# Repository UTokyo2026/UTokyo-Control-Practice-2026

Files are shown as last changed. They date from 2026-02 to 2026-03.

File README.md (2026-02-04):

# Wheeled Inverted Pendulum - Course Materials

Course materials for the Wheeled Inverted Pendulum practical exercise at the University of Tokyo, Department of Precision Engineering.

## 📁 Contents

### 📄 Lecture notes (English)
- **text2026_en.pdf** – Full lecture text (English) for the Wheeled Inverted Pendulum exercise. Same content as the printed handout; all appendix PDFs are embedded. Update this file from the LaTeX build when you release a new version (see “Keeping the PDF in sync” below).

### 🛠️ debug_tools/
Debugging and visualization tools with complete documentation:

- **1_motor_controller/** - Interactive motor testing tool
- **2_analog_input_visualizer/** - 4-channel analog input visualization
- **3_six_channel_oscilloscope/** - Complete inverted pendulum control program with 6-channel real-time visualization

Each tool includes:
- `.cpp` - mbed source code
- `.bin` - Pre-compiled binary (ready to flash)
- `.pde` - Processing visualization program
- `README.md` / `README.pdf` - Complete documentation

### 📚 appendix/
All appendix materials (same as in the lecture notes):

- **Datasheets:** `AE-drv8832_a.pdf`, `Circuit_diagram.pdf`, `LD1117V33.pdf`, `RE280ra.pdf`, `TPR-105f.pdf`
- `parts_list.pdf` - Parts list
- `processing_oscilloscope_manual.pdf` - Processing installation and oscilloscope manual

### 📊 matlab_simulink/
MATLAB/Simulink models for simulation and controller design (to be added)

### 🎥 video/
Demonstration videos of working inverted pendulum

## 🚀 Quick Start

### Using the Complete Control Program

1. **Flash to mbed:**
   ```
   debug_tools/3_six_channel_oscilloscope/3_six_channel_oscilloscope.bin
   ```
   Drag and drop this file to your mbed USB drive.

2. **Run visualization:**
   Open `3_six_channel_oscilloscope.pde` in Processing and click Run.

3. **Reset mbed** to synchronize the display.

### Understanding the Code

Open `3_six_channel_oscilloscope.cpp` to see the complete implementation:
- Lines 3-11: Control parameters (KP, KD, VLIMIT, etc.)
- Lines 70-132: Main control loop (PD control algorithm)
- Lines 134-161: Initialization and startup

### Adjusting Parameters

Edit the `#define` values at the top of `3_six_channel_oscilloscope.cpp`:

```cpp
#define SAMP_FREQ 2000.0f  // Sampling frequency (Hz)
#define VLIMIT 0.1f        // Motor voltage limit (0-1)
#define VOFFSET 0.0f       // Friction compensation
#define KP 1.0f            // Proportional gain
#define KD 0.0f            // Derivative gain
```

Then recompile in Keil Studio Cloud and flash the new `.bin` file.

## 📖 Documentation

Detailed documentation is available in the `debug_tools/` folder:

- **Main README:** `debug_tools/README.md` - Overview of all tools
- **Tool-specific READMEs:** Each tool has its own detailed documentation

All READMEs are available in both Markdown (`.md`) and PDF (`.pdf`) formats.

## 🔧 Requirements

### Hardware
- mbed LPC1768 microcontroller
- DRV8832 motor driver module
- RE-280RA DC motor
- TPR-105F photo-interrupters (×2)
- LD1117V33 voltage regulator
- Battery pack and other components (see circuit diagram)

### Software
- [Keil Studio Cloud](https://studio.keil.arm.com/) - For compiling mbed programs
- [Processing](https://processing.org/download) - For visualization tools
- [MATLAB/Simulink](https://www.mathworks.com/) - For simulation (optional)

## 📝 License

These materials are provided for educational purposes as part of the University of Tokyo Precision Engineering practical exercise course.

## 🎓 Course Information

- **Course:** Practical Exercise in Precision Engineering
- **Institution:** University of Tokyo, Department of Precision Engineering
- **Academic Year:** 2026 S1S2

## 📧 Support

For questions or issues:
1. Check the README files in `debug_tools/`
2. Review the circuit diagram in `appendix/`
3. Consult the course lecture notes
4. Ask your instructor or TA

## 🔗 Related Resources

- [mbed Documentation](https://os.mbed.com/docs/)
- [Processing Documentation](https://processing.org/reference/)
- [DRV8832 Datasheet](https://www.ti.com/product/DRV8832)

---

**Last Updated:** February 2026  
**Version:** 2026.1

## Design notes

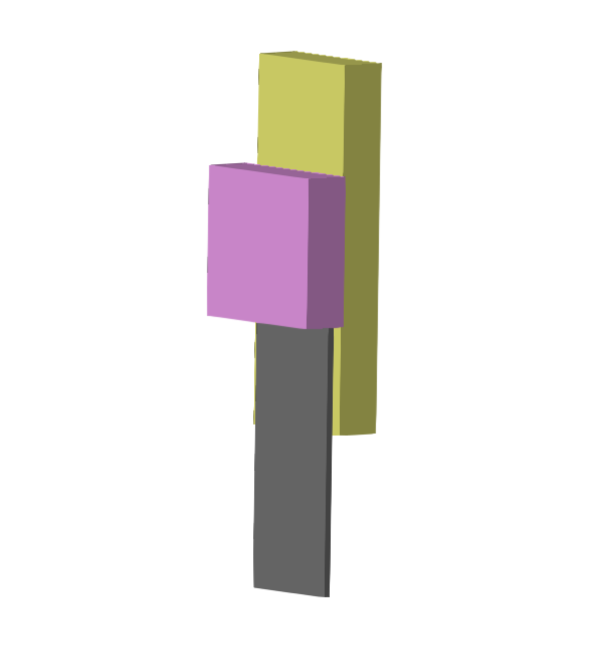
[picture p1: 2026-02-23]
matlab_simulink/Body.png

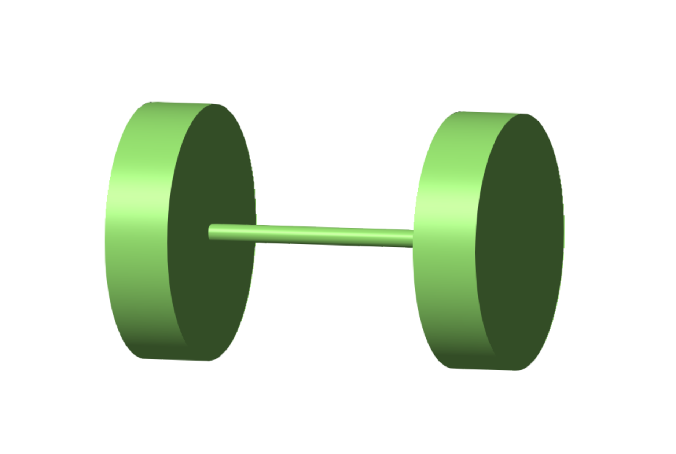
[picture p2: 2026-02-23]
matlab_simulink/Wheel.png

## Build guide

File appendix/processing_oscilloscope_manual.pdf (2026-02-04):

## 簡易オシロスコープの使い方

【事前インストール作業】
1. （Windows のみ）mbed シリアルポートドライバをインストール

https://os.mbed.com/handbook/Windows-serial-configuration こちらのページからドライバをダウンロードし，指示に従ってインストールしてください．
2. Processing のインストール

https://processing.org/
こちらから Processing をダウンロードしてインストールしてください（ZIP ファイルを解凍して，好 きなフォルダに設置するだけです）．最初から自分のパソコンに Processing が入っている人は，Ver. 3 系であることを確認してください．Ver. 2 系と Ver. 3 系は，一部互換性がありません．
3. オシロスコーププログラムの設置
Google Drive の plotter6ch (https://drive.google.com/drive/folders/17Zr5LieNyZgATRA_iedG5hgk1iPhXVAk?usp=sharing) の中にある 2 つのファイルをダウンロードします．自分のパソコンの中 に（場所はどこでも良いので）plotter6ch という名称のフォルダを作り，その中にダウンロードした 2 個のファイルを入れてください．Processing は，フォルダ名とプログラムファイル名が同じで無い と動作しませんので，フォルダ名を必ず “plotter6ch” としてください．

【使い方】
◼ | Mbed に制御用プログラムをコンパイルしてダウンロードし，パソコンと USB 接続します．
| plotter6ch.pde（環境により拡張子は表示されないかもしれません）をダブルクリックで開き，下
| 図赤丸の部分（丸に三角形の実行ボタン）を押すと，簡易オシロスコープが立ち上がります．
| （【Windows】初回のみ，右クリック→プログラムから開く→Processing）

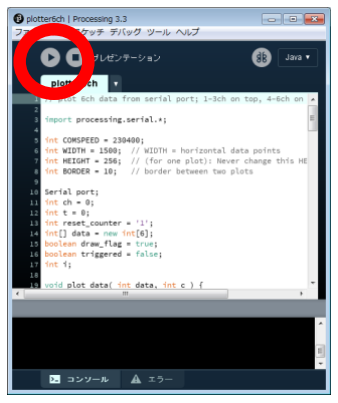
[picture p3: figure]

実行ボタンを押したときに，次ページに示すオシロスコープ画面が出ない人や，エラーで止まって しまう人は，Processing ウィンドウ下部の console 画面をみてください．そこに，パソコンの中に あるシリアルポートの一覧が出ています．例えば，Mac の場合だと

[0] “dev/cu.Bluetooth-Incoming-Port”
[1] “dev/tty.Bluetooth-Incoming-Port”
[2] “dev/tty.usbmodem1412”
などと表示されますので，”dev/tty.usbmodemXXXX” (XXXX は数字が入る)を探してください．そ のポートの番号（行頭にある[3]などの数字）を，プログラムの 63 行目に書き込みます．

port = new Serial( this, Serial.list()[0], COMSPEED);
下線部の 0 となっている部分を書き換えてください．
Windows の人は，表示されるポートを上から（0 番から）順に試してみてください．

◼ | 画面は上下に 2 分割されています．上半分に１～３チャンネルが，下半分に４～６チャンネルが，
| それぞれ（赤，緑，青）の順で表示されます．

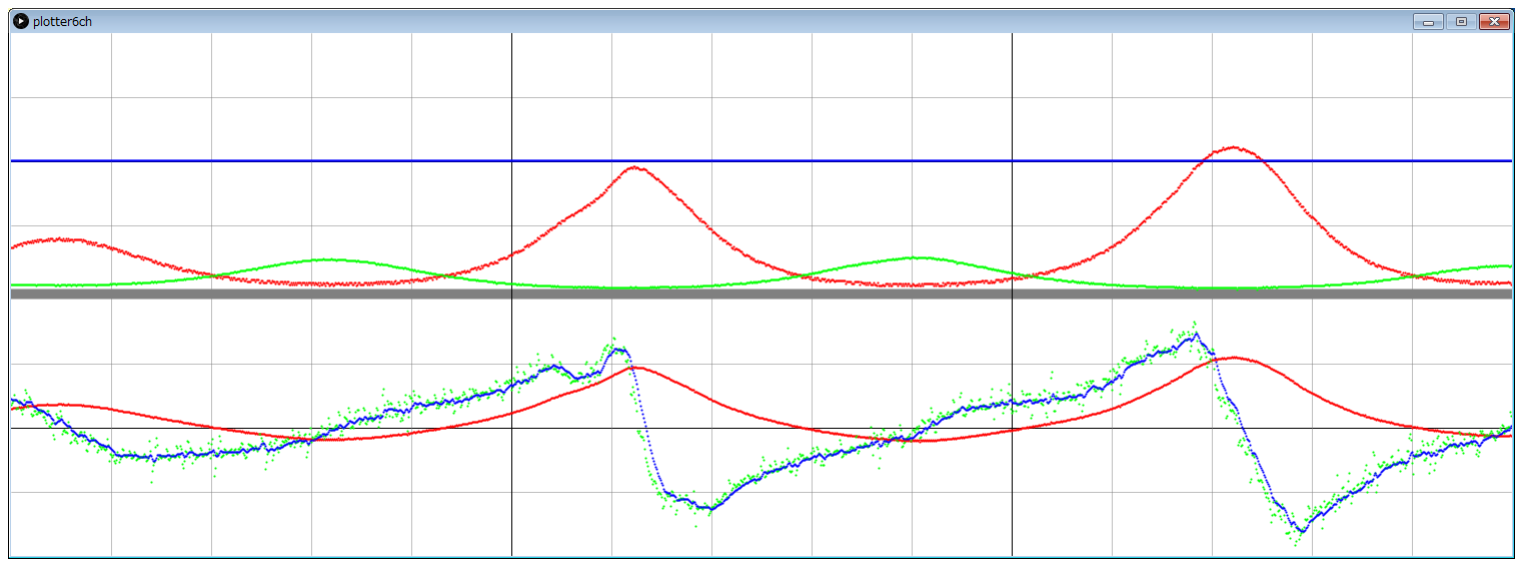
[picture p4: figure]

◼ | オシロスコープが動作している最中に MBED をリセットすることで，チャンネル順序が正しい順 序にリセットされます（MBED 側のプログラムで書いた順に１～６チャンネルになります）． リセットしていない状況では，チャンネル順序は意図した順序になっていない場合があります．
◼ | 画面上でクリックすると，現在の描画が右端まで進んだところで描画が停止します．また，スクリ ーンショットが，data.png という名前で保存されます（同名ファイルがある場合は上書きされま す）．再度画面上でクリックすると，再び画面の更新が始まります． スクリーンショットの保存先は，plotter6ch フォルダです．
◼ | 標準では画面の横幅は 1500 点です．MBED プログラムが 2000Hz で動いている場合，画面の横幅 は 0.75 秒に相当します．
◼ | 各データは 1 バイト（0-255）のデータとして送受信されています．MBED 側から送信する際には， データを 0-255 の範囲に整えた上で，char 型に cast してください．画面表示は，上下それぞれに おいて，一番下が 0，一番上が 255 になります．
◼ | この簡易オシロスコーププログラムは，毎制御周期に必ず 6 個のデータ（かつ，全て 1 バイトデー タ）が送られてくるという想定で動いています．MBED 側からは，（必要が無い場合でも）必ず６ チャンネル分のデータを送ってください．そうしないと，おかしなグラフになります．

1-3 CH

4-6 CH

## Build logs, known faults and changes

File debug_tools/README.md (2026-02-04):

# Debug Tools for Inverted Pendulum

This directory contains three debugging tools for the wheeled inverted pendulum experiment. Each tool consists of:
- **`.cpp` file**: mbed microcontroller program (C++ source code)
- **`.bin` file**: Pre-compiled binary ready to flash to mbed LPC1768
- **`.pde` file**: Processing visualization program (runs on PC)

## Tools Overview

### 1. Motor Controller (`motor_controller/`)
**Purpose**: Test motor driver circuit and control motor interactively

**mbed Program** (`motor_controller.cpp`):
- Receives commands via USB serial (115200 baud)
- Commands:
  - `F xx` - Forward at xx% duty cycle (0-100)
  - `B xx` - Backward at xx% duty cycle (0-100)
  - `S` - Stop motor
- Pin connections:
  - `p13`: Motor forward signal
  - `p14`: Motor reverse signal
  - `p18`: Motor PWM voltage (AnalogOut)

**Processing Visualizer** (`motor_controller.pde`):
- Provides GUI with sliders and buttons
- Displays real-time motor status
- Sends commands to mbed via serial

**Usage**:
1. Flash `motor_controller.bin` to mbed (or compile `.cpp` yourself)
2. Connect motor driver circuit
3. Run `motor_controller.pde` in Processing
4. Use GUI to test motor operation

---

### 2. Analog Input Visualizer (`analog_input_visualizer/`)
**Purpose**: Visualize 4 analog input channels in real-time

**mbed Program** (`analog_input_visualizer.cpp`):
- Reads 4 analog inputs at ~200 Hz
- Sends data via USB serial (115200 baud)
- Uses frame-based protocol: `[0xAA 0x55] + 4 bytes`
- Pin connections:
  - `p16`: Analog input CH1
  - `p17`: Analog input CH2
  - `p19`: Analog input CH3 (photo-interrupter 1)
  - `p20`: Analog input CH4 (photo-interrupter 2)

**Processing Visualizer** (`analog_input_visualizer.pde`):
- Displays 4-channel real-time waveforms
- Shows pendulum angle graphically
- Helps verify sensor alignment and operation

**Usage**:
1. Flash `analog_input_visualizer.bin` to mbed
2. Connect analog sensors to inputs (p16-p20)
3. Run `analog_input_visualizer.pde` in Processing
4. Observe real-time sensor readings

---

### 3. Six-Channel Oscilloscope (`six_channel_oscilloscope/`)
**Purpose**: Monitor complete control system with 6 data channels

**mbed Program** (`six_channel_oscilloscope.cpp`):
- Implements full PD control loop at 2000 Hz
- Reads angle sensors (2 photo-interrupters)
- Controls motor based on feedback
- Sends 6 channels of data via USB serial (230400 baud)
- Uses frame-based protocol: `[0xAA 0x55] + 6 bytes`
- Data channels:
  1. Photo-interrupter 1 output
  2. Photo-interrupter 2 output
  3. Angle (difference of sensors)
  4. Angular velocity (ω)
  5. Filtered angular velocity
  6. Reference line (128)

**Processing Visualizer** (`six_channel_oscilloscope.pde`):
- Displays 6 channels in two 3-channel plots
- Upper plot: CH1 (Red), CH2 (Green), CH3 (Blue)
- Lower plot: CH4 (Red), CH5 (Green), CH6 (Blue)
- Essential for tuning control parameters

**Usage**:
1. Flash `six_channel_oscilloscope.bin` to mbed
2. Connect complete circuit (motor + sensors)
3. Run `six_channel_oscilloscope.pde` in Processing
4. Reset mbed to synchronize display
5. Tune PD gains while monitoring system response

---

## How to Use

### Option 1: Use Pre-compiled Binaries (Easiest)
1. Connect mbed LPC1768 to PC via USB
2. mbed appears as USB drive (e.g., `MBED` or `LPC1768`)
3. Drag and drop `.bin` file to mbed drive
4. Press reset button on mbed
5. Run corresponding `.pde` file in Processing

### Option 2: Compile from Source
If you want to modify the programs or understand the code:

1. **For mbed programs**:
   - Use [Keil Studio Cloud](https://studio.keil.arm.com/) (online IDE)
   - Or use [mbed CLI](https://os.mbed.com/docs/mbed-os/latest/build-tools/index.html) locally
   - Import mbed-os library
   - Compile `.cpp` file
   - Download generated `.bin` file
   - Flash to mbed

2. **For Processing programs**:
   - Install [Processing](https://processing.org/download)
   - Open `.pde` file
   - Click Run (▶) button
   - Select correct serial port in code if needed

---

## Serial Communication Protocol

All tools use USB serial communication between mbed and PC:

### Basic Principle
- **UART (Universal Asynchronous Receiver-Transmitter)**: Serial protocol for byte-by-byte data transmission
- **USB-to-Serial**: mbed LPC1768 has built-in USB-to-serial converter
- **Pins**: `USBTX` and `USBRX` connect to USB interface
- **Baud Rate**: Communication speed (bits per second)
  - Motor Controller: 115200 bps
  - Analog Input Visualizer: 115200 bps
  - Oscilloscope: 230400 bps (higher for 2 kHz data rate)

### Frame-Based Protocol (Visualizers)
To reliably transmit multiple data values, a frame-based protocol is used:

```
[Header: 0xAA 0x55] [Data Byte 1] [Data Byte 2] ... [Data Byte N]
```

- **Frame Header**: Two special bytes (`0xAA 0x55`) mark start of frame
- **Data Bytes**: Each sensor/variable value encoded as 0-255
- **Synchronization**: Processing searches for header pattern to align data stream

### Text-Based Protocol (Motor Controller)
Simple ASCII commands for human readability:
- Commands sent as text strings (e.g., `"F 50\n"`)
- Easy to test with any serial terminal
- mbed parses commands using `sscanf()`

---

## Pin Assignments Summary

| Function | Pin | Type | Used By |
|---|-----|---|---|
| Motor Forward | p13 | DigitalOut | Motor Controller, Oscilloscope |
| Motor Reverse | p14 | DigitalOut | Motor Controller, Oscilloscope |
| Motor Voltage | p18 | AnalogOut | Motor Controller, Oscilloscope |
| Analog CH1 | p16 | AnalogIn | Analog Input Visualizer |
| Analog CH2 | p17 | AnalogIn | Analog Input Visualizer |
| Photo-interrupter 1 | p19 | AnalogIn | Analog Input Visualizer, Oscilloscope |
| Photo-interrupter 2 | p20 | AnalogIn | Analog Input Visualizer, Oscilloscope |
| USB Serial TX | USBTX | Serial | All tools |
| USB Serial RX | USBRX | Serial | All tools |

**Note**: `p18` is the only AnalogOut pin on mbed LPC1768, so motor voltage control must use this pin.

---

## Troubleshooting

### mbed not recognized as USB drive
- Try different USB cable (some cables are power-only)
- Press reset button on mbed
- Check USB port on PC

### Processing cannot find serial port
- Check port name in `.pde` file (usually auto-detected)
- On Windows: Look for `COM3`, `COM4`, etc.
- On macOS: Look for `/dev/tty.usbmodem*`
- On Linux: Look for `/dev/ttyACM*`
- Ensure no other program is using the port

### No data displayed in Processing
- Reset mbed after starting Processing program
- Check baud rate matches between mbed and Processing
- Verify USB cable supports data (not just power)

### Motor moves opposite direction
- Swap motor driver connections (`p13` ↔ `p14`)
- Or swap motor wire polarity

### Sensor readings look wrong
- Check sensor power supply (3.3V, not 5V)
- Verify pull-up resistors are installed
- Adjust sensor alignment mechanically
- Check resistor values (typical: 1kΩ - 12kΩ)

---

## Modifying the Programs

### Changing Control Parameters (Oscilloscope)
Edit these `#define` values in `six_channel_oscilloscope.cpp`:

```cpp
#define SAMP_FREQ 2000.0f  // Sampling frequency (Hz)
#define VLIMIT 0.1f        // Motor voltage limit
#define KP 1.0f            // Proportional gain
#define KD 0.0f            // Derivative gain
```

After changing, recompile and flash to mbed.

### Adding More Channels
The frame protocol can be extended:
1. Add more data bytes in mbed program after frame header
2. Update Processing to read additional bytes
3. Add visualization for new channels

### Changing Serial Baud Rate
Must match in both mbed and Processing:

**mbed**: `pc.baud(115200);`  
**Processing**: `myPort = new Serial(this, portName, 115200);`

---

## Further Reading

- [mbed Serial API](https://os.mbed.com/docs/mbed-os/latest/apis/serial-uart-apis.html)
- [Processing Serial Library](https://processing.org/reference/libraries/serial/index.html)
- [UART Communication Basics](https://learn.sparkfun.com/tutorials/serial-communication)

---

## License

These tools are provided for educational purposes as part of the University of Tokyo wheeled inverted pendulum experiment.

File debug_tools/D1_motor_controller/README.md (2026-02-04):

# Motor Controller Debug Tool

## Purpose
Interactive tool for testing motor driver circuit and controlling motor speed/direction without modifying code.

## Files

### 1_motor_controller.cpp (mbed program)
**What it does:**
- Receives text commands via USB serial communication
- Controls motor based on received commands
- Provides simple command-line interface for motor testing

**Pin Connections:**
- `p13` (DigitalOut): Motor forward signal → connects to motor driver IN1
- `p14` (DigitalOut): Motor reverse signal → connects to motor driver IN2
- `p18` (AnalogOut): Motor PWM voltage → connects to motor driver VSET
- `USBTX/USBRX`: USB serial communication (built-in)

**Serial Settings:**
- Baud rate: 115200 bps
- Protocol: Text-based ASCII commands

**Commands:**
```
F xx    Forward at xx% duty cycle (0-100)
        Example: "F 50" → forward at 50% speed

B xx    Backward at xx% duty cycle (0-100)
        Example: "B 30" → backward at 30% speed

S       Stop motor
        Example: "S" → stop immediately
```

**How it works:**
1. Program waits for characters from serial port
2. When newline (`\n`) is received, parses the command
3. Extracts command letter (F/B/S) and optional value
4. Applies corresponding motor control:
   - Forward: sets `motor_f=1`, `motor_r=0`, `motor_v=duty`
   - Backward: sets `motor_f=0`, `motor_r=1`, `motor_v=duty`
   - Stop: sets `motor_f=0`, `motor_r=0`, `motor_v=0`
5. Sends confirmation message back via serial

### 1_motor_controller.bin (pre-compiled binary)
**What it is:**
- Compiled executable file for mbed LPC1768
- Contains machine code ready to run on microcontroller

**How to use:**
1. Connect mbed to PC via USB
2. mbed appears as USB drive (e.g., "MBED" or "LPC1768")
3. Drag and drop `1_motor_controller.bin` onto mbed drive
4. LED on mbed flashes during programming
5. Press reset button on mbed to start program

**Why use .bin instead of .cpp:**
- No compilation needed—instant deployment
- Guaranteed to work (already tested and compiled)
- Faster workflow for testing

**When to compile .cpp yourself:**
- Want to change pin assignments
- Need to modify commands or add features
- Want to adjust motor control logic
- Learning how the code works

### 1_motor_controller.pde (Processing visualizer)
**What it does:**
- Provides graphical user interface (GUI) for motor control
- Displays real-time motor status
- Sends commands to mbed via serial

**Features:**
- Sliders for adjusting motor speed (0-100%)
- Buttons for forward/backward/stop
- Real-time display of current motor state
- Visual feedback of PWM duty cycle
- Direction indicator

**How to use:**
1. Install Processing from https://processing.org/download
2. Open `1_motor_controller.pde` in Processing
3. Check serial port name in code (usually auto-detected)
4. Click Run button (▶) to start GUI
5. Use sliders and buttons to control motor

## Usage Workflow

### Quick Start (using .bin file):
1. Flash `1_motor_controller.bin` to mbed
2. Connect motor driver circuit to mbed:
   - p13 → motor driver IN1
   - p14 → motor driver IN2
   - p18 → motor driver VSET
3. Connect motor to driver output
4. Connect power supply
5. Run `1_motor_controller.pde` in Processing
6. Use GUI to test motor

### Advanced (compiling from source):
1. Open Keil Studio Cloud (https://studio.keil.arm.com/)
2. Create new project for mbed LPC1768
3. Import mbed-os library
4. Copy contents of `1_motor_controller.cpp`
5. Compile and download .bin file
6. Flash to mbed as above

## Testing Checklist

Use this tool to verify:
- [ ] Motor rotates forward when commanded
- [ ] Motor rotates backward when commanded
- [ ] Motor speed changes with PWM duty cycle
- [ ] Motor stops completely when commanded
- [ ] No abnormal heating of motor driver IC
- [ ] Power supply voltage remains stable
- [ ] No excessive current draw

## Troubleshooting

**Motor doesn't move:**
- Check battery/power supply is on
- Verify motor driver connections
- Check motor wires are connected
- Ensure mbed is programmed correctly (reset after flashing)

**Motor moves opposite direction:**
- Swap p13 and p14 connections
- Or swap motor wire polarity

**Processing can't connect:**
- Check serial port name in .pde file
- Ensure no other program is using the port
- Try different USB cable (must support data)
- On Windows: look for COM3, COM4, etc.
- On macOS: look for /dev/tty.usbmodem*
- On Linux: look for /dev/ttyACM*

**Motor runs but speed doesn't change:**
- Check p18 (AnalogOut) connection to VSET
- Verify PWM duty cycle is being sent correctly
- Check motor driver power supply

## Technical Details

### Text-Based Protocol
The motor controller uses a simple text-based protocol for human readability:

**Advantages:**
- Easy to test with any serial terminal (PuTTY, screen, etc.)
- Human-readable for debugging
- Simple to parse with `sscanf()`

**Format:**
```
<COMMAND> <VALUE>\n
```
- Commands are single letters (F/B/S)
- Value is optional integer (0-100 for F/B)
- Newline terminates command

**Example transmission:**
```
F 50\n    → Forward 50%
B 30\n    → Backward 30%
S\n       → Stop
```

### Motor Control Logic

**Forward motion:**
```cpp
motor_f = 1;      // Enable forward
motor_r = 0;      // Disable reverse
motor_v = duty;   // Set PWM duty cycle
```

**Backward motion:**
```cpp
motor_f = 0;      // Disable forward
motor_r = 1;      // Enable reverse
motor_v = duty;   // Set PWM duty cycle
```

**Stop:**
```cpp
motor_f = 0;      // Disable forward
motor_r = 0;      // Disable reverse
motor_v = 0.0f;   // Zero voltage
```

### PWM Voltage Output
- `motor_v` is AnalogOut (0.0 to 1.0)
- 0.0 = 0V, 1.0 = 3.3V
- Motor driver amplifies this: V_motor = 3.3V × motor_v × 4
- Example: motor_v = 0.5 → V_motor ≈ 6.6V

## Modifying the Code

### Change pin assignments:
```cpp
DigitalOut motor_f(p21);  // Change from p13 to p21
DigitalOut motor_r(p22);  // Change from p14 to p22
// Note: p18 is the only AnalogOut, cannot change
```

### Add new commands:
```cpp
else if (cmd == 'T' || cmd == 't') {
    // Test mode: alternate forward/backward
    apply_fwd(50);
    wait(1);
    apply_bwd(50);
    wait(1);
    apply_stop();
}
```

### Change baud rate:
```cpp
pc.baud(9600);  // Change from 115200 to 9600
```
(Must also change in Processing .pde file)

## Safety Notes

⚠️ **Important:**
- Always test with low duty cycles first (10-20%)
- Monitor motor driver temperature
- Ensure power supply can provide sufficient current
- Disconnect motor when not testing
- Turn off power between tests to save battery

## See Also
- Main README: `../README.md`
- mbed Serial API: https://os.mbed.com/docs/mbed-os/latest/apis/serial-uart-apis.html
- DRV8832 Datasheet: See appendix in main document

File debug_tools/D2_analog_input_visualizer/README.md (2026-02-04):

# Analog Input Visualizer Debug Tool

## Purpose
Real-time visualization of 4 analog input channels. Versatile tool for monitoring any analog sensors including:
- Photo-interrupters (angle sensors)
- Encoder signals (can use CH1/CH2 for encoder A/B)
- Potentiometers
- Voltage sensors
- Any 0-3.3V analog signals

## Files

### 2_analog_input_visualizer.cpp (mbed program)
**What it does:**
- Reads 4 analog input channels at approximately 200 Hz
- Converts analog readings (0.0-1.0) to 8-bit values (0-255)
- Transmits data via USB serial using frame-based protocol
- Universal tool for any analog sensors: photo-interrupters, encoders, potentiometers, etc.

**Pin Connections:**
- `p16` (AnalogIn): Channel 1 - General analog input (can be used for encoder A)
- `p17` (AnalogIn): Channel 2 - General analog input (can be used for encoder B)
- `p19` (AnalogIn): Channel 3 - General analog input (typically photo-interrupter 1 for angle)
- `p20` (AnalogIn): Channel 4 - General analog input (typically photo-interrupter 2 for angle)
- `USBTX/USBRX`: USB serial communication (built-in)

**Serial Settings:**
- Baud rate: 115200 bps
- Protocol: Frame-based binary transmission

**Data Frame Format:**
```
[0xAA] [0x55] [CH1] [CH2] [CH3] [CH4]
 ^^^^   ^^^^   ^^^   ^^^   ^^^   ^^^
Header Header Data  Data  Data  Data
(2 bytes)     (4 bytes, each 0-255)
```

**Sampling Rate:**
- Approximately 200 Hz (5 ms delay between frames)
- Fast enough for pendulum motion tracking
- Slow enough for reliable serial transmission

**How it works:**
1. Main loop reads 4 analog inputs using `AnalogIn.read()`
2. Each reading (float 0.0-1.0) is converted to uint8 (0-255)
3. Frame header (0xAA 0x55) is sent first
4. Four data bytes are sent in order (CH1-CH4)
5. 5 ms delay before next frame
6. Processing searches for header pattern to synchronize

### 2_analog_input_visualizer.bin (pre-compiled binary)
**What it is:**
- Pre-compiled executable for mbed LPC1768
- Ready to flash without compilation

**How to use:**
1. Connect mbed to PC via USB
2. Drag and drop `2_analog_input_visualizer.bin` onto mbed drive
3. Press reset button on mbed
4. Program starts transmitting analog input data

**When to compile .cpp yourself:**
- Want to change sampling rate (modify `wait_ms(5)`)
- Need different pin assignments
- Want to add more channels
- Need to modify data scaling or filtering

### 2_analog_input_visualizer.pde (Processing visualizer)
**What it does:**
- Receives data frames from mbed via serial
- Displays 4-channel real-time waveforms
- Can calculate and display pendulum angle (if using photo-interrupters)
- Can show encoder signals (if using encoder inputs)
- Flexible visualization for any analog sensor data

**Features:**
- 4 synchronized time-series plots
- Color-coded channels for easy identification
- Automatic scaling and scrolling
- Frame synchronization using header detection
- Visual pendulum angle indicator (graphical representation)

**How to use:**
1. Install Processing from https://processing.org/download
2. Open `2_analog_input_visualizer.pde` in Processing
3. Verify serial port name in code (usually auto-detected)
4. Click Run button (▶) to start visualization
5. Reset mbed to synchronize display
6. Manually move pendulum to observe sensor response

## Usage Workflow

### Quick Start:
1. **Connect sensors to mbed:**
   - Photo-interrupter 1 output → p19
   - Photo-interrupter 2 output → p20
   - Sensor power: 3.3V (not 5V!)
   - Install pull-up resistors (typically 1kΩ - 12kΩ)

2. **Flash program:**
   - Copy `angle_sensor_visualizer.bin` to mbed USB drive
   - Press reset button

3. **Run visualizer:**
   - Open `angle_sensor_visualizer.pde` in Processing
   - Click Run (▶)
   - Reset mbed to synchronize

4. **Test sensors:**
   - Manually rotate pendulum slowly
   - Observe waveforms change
   - Verify angle calculation is correct
   - Check for noise or signal issues

## Testing Checklist

Use this tool to verify:
- [ ] Sensor outputs change as pendulum moves
- [ ] Both sensors produce clean signals (not too noisy)
- [ ] Angle calculation corresponds to actual position
- [ ] Sensors detect full range of motion (±30° or more)
- [ ] No signal saturation (outputs not stuck at 0 or 255)
- [ ] Sensor alignment is mechanically correct
- [ ] No interference from motor or other circuits

## Troubleshooting

**No data displayed:**
- Check serial port name in .pde file
- Reset mbed after starting Processing
- Verify USB cable supports data (not power-only)
- Check baud rate matches (115200)

**Noisy or erratic signals:**
- Check sensor power supply (should be stable 3.3V)
- Verify pull-up resistors are installed
- Route sensor wires away from motor power lines
- Check for loose connections on breadboard
- Try different resistor values (1kΩ - 12kΩ range)

**Sensor output saturated (stuck at 0 or 255):**
- Resistor value too high or too low
- For high output (255): decrease resistor value
- For low output (0): increase resistor value
- Typical range: 3kΩ - 10kΩ for photo-interrupters

**Angle calculation seems wrong:**
- Check sensor mechanical alignment
- Verify sensors are 90° apart (or appropriate spacing)
- Adjust sensor mounting bracket carefully
- Ensure encoder disk/slit is properly positioned

**Processing crashes or freezes:**
- Close and restart Processing
- Check for serial port conflicts
- Ensure mbed is properly programmed
- Try different USB port

## Technical Details

### Frame-Based Protocol

**Why use frame headers?**
- Serial data is a continuous stream of bytes
- Without headers, impossible to know where each frame starts
- Headers (0xAA 0x55) are unlikely to appear in normal data
- Processing searches for this pattern to synchronize

**Synchronization algorithm:**
```
1. Read byte from serial
2. If byte == 0xAA:
   3. Read next byte
   4. If next byte == 0x55:
      5. Read 4 data bytes (CH1-CH4)
      6. Display data
   7. Else: go back to step 1
8. Else: go back to step 1
```

**Data encoding:**
```cpp
// Convert float (0.0-1.0) to uint8 (0-255)
uint8_t float_to_u8(float x) {
    if (x < 0.0f) x = 0.0f;
    if (x > 1.0f) x = 1.0f;
    return (uint8_t)(x * 255.0f + 0.5f);
}
```
- Analog reading: 0.0 → 0V, 1.0 → 3.3V
- Transmitted value: 0 → 0V, 255 → 3.3V
- Resolution: 3.3V / 255 ≈ 13 mV per step

### Angle Calculation

For two photo-interrupters measuring pendulum angle:

**Differential measurement:**
```
angle = sensor1 - sensor2
```
- When pendulum is vertical: sensor1 ≈ sensor2 → angle ≈ 0
- When pendulum tilts right: sensor1 > sensor2 → angle > 0
- When pendulum tilts left: sensor1 < sensor2 → angle < 0

**Angular velocity:**
```
omega = (angle - angle_prev) × sampling_frequency
```
- Derivative approximation using finite difference
- Sampling frequency ≈ 200 Hz
- Units: arbitrary (proportional to rad/s)

### Photo-Interrupter Operation

**How it works:**
1. LED emits infrared light
2. Light reflects off encoder disk (white/reflective areas)
3. Phototransistor detects reflected light
4. Output voltage proportional to light intensity
5. Bright reflection → high voltage (near 3.3V)
6. Dark area → low voltage (near 0V)

**Pull-up resistor:**
```
3.3V ──┬── Resistor ──┬── Phototransistor ── GND
       │              │
       └─ To mbed pin ┘
```
- Resistor value determines sensitivity
- Higher R → higher voltage, more sensitive, may saturate
- Lower R → lower voltage, less sensitive, more noise-resistant
- Typical: 3kΩ - 10kΩ for this application

## Modifying the Code

### Change sampling rate:
```cpp
wait_ms(5);   // 200 Hz → change to wait_ms(10) for 100 Hz
```

### Add more channels:
```cpp
AnalogIn ch5(p15);  // Add new channel

// In main loop:
float v5 = ch5.read();
pc.putc(float_to_u8(v5));  // Send after CH4
```
(Must also update Processing to read 5 bytes)

### Change pin assignments:
```cpp
AnalogIn ch1(p15);  // Change from p16 to p15
AnalogIn ch2(p16);  // Change from p17 to p16
// etc.
```

### Add filtering:
```cpp
// Simple moving average filter
float v1_filtered = 0.9f * v1_prev + 0.1f * v1;
v1_prev = v1_filtered;
```

### Change baud rate:
```cpp
pc.baud(230400);  // Change from 115200 to 230400
```
(Must also change in Processing .pde file)

## Sensor Alignment Procedure

1. **Mechanical setup:**
   - Mount sensors on L-bracket
   - Position encoder disk between sensor gaps
   - Ensure disk can rotate freely without rubbing

2. **Electrical verification:**
   - Power on circuit (battery box or USB)
   - Run visualizer
   - Check all channels show reasonable values (not 0 or 255)

3. **Alignment test:**
   - Hold pendulum vertical
   - Observe CH3 and CH4 waveforms
   - Both should be approximately equal when vertical
   - Adjust sensor bracket angle if needed

4. **Range test:**
   - Rotate pendulum through full range (±30° or more)
   - Verify sensors respond throughout range
   - Check for dead zones or saturation

5. **Noise check:**
   - Hold pendulum still
   - Observe signal stability
   - Some noise is acceptable, but excessive noise indicates issues

## Safety Notes

⚠️ **Important:**
- Use 3.3V for sensor power (not 5V) - mbed inputs are 3.3V logic
- Do not force encoder disk - it should rotate freely
- Be gentle with universal board - it breaks easily
- Route sensor wires away from motor power lines
- Check connections before powering on

## See Also
- Main README: `../README.md`
- mbed AnalogIn API: https://os.mbed.com/docs/mbed-os/latest/apis/analogin.html
- Processing Serial Library: https://processing.org/reference/libraries/serial/
- Photo-interrupter datasheet: See appendix in main document (TPR-105F)

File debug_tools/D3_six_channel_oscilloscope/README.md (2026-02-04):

# Six-Channel Oscilloscope Debug Tool

## Purpose
Comprehensive real-time monitoring tool for the complete inverted pendulum control system. Displays 6 channels of data simultaneously, essential for tuning control parameters and debugging feedback control.

## Files

### 3_six_channel_oscilloscope.cpp (mbed program)
**What it does:**
- Implements complete PD (Proportional-Derivative) control loop
- Reads angle sensors (2 photo-interrupters)
- Calculates angle and angular velocity
- Controls motor based on feedback
- Transmits 6 channels of data at 2000 Hz via serial
- Provides real-time control and monitoring

**Pin Connections:**
- `p13` (DigitalOut): Motor forward signal
- `p14` (DigitalOut): Motor reverse signal
- `p18` (AnalogOut): Motor PWM voltage
- `p19` (AnalogIn): Photo-interrupter 1 (angle sensor)
- `p20` (AnalogIn): Photo-interrupter 2 (angle sensor)
- `LED1-LED4`: Status indicators (blink, voltage over, forward, backward)
- `USBTX/USBRX`: USB serial communication (built-in)

**Serial Settings:**
- Baud rate: 230400 bps (higher than other tools due to 2 kHz data rate)
- Protocol: Frame-based binary transmission

**Control Parameters (editable at top of file):**
```cpp
#define SAMP_FREQ 2000.0f   // Sampling frequency (Hz)
#define VLIMIT 0.1f         // Motor voltage limit (0.0-1.0)
#define VOFFSET 0.0f        // Motor offset voltage
#define KP 1.0f             // Proportional gain
#define KD 0.0f             // Derivative gain
```

**Data Frame Format:**
```
[0xAA] [0x55] [CH1] [CH2] [CH3] [CH4] [CH5] [CH6]
 ^^^^   ^^^^   ^^^   ^^^   ^^^   ^^^   ^^^   ^^^
Header Header Data  Data  Data  Data  Data  Data
(2 bytes)     (6 bytes, each 0-255)
```

**6 Data Channels:**
1. **CH1**: Photo-interrupter 1 output (0.0-1.0 → 0-255)
2. **CH2**: Photo-interrupter 2 output (0.0-1.0 → 0-255)
3. **CH3**: Angle (pd1 - pd2, centered at 128)
4. **CH4**: Angular velocity ω (scaled, centered at 128)
5. **CH5**: Filtered angular velocity (scaled, centered at 128)
6. **CH6**: Reference line (fixed at 128)

**How the control loop works:**
```
Every 1/2000 second (500 μs):
1. Read sensors (pd1, pd2)
2. Calculate angle = pd1 - pd2
3. Calculate angular velocity = (angle - angle_prev) × SAMP_FREQ
4. Apply optional filtering to angular velocity
5. Calculate control output = KP × angle + KD × filtered_omega
6. Determine motor direction (forward if v_out > 0, else backward)
7. Limit voltage to VLIMIT
8. Apply voltage to motor
9. Update LED indicators
10. Send 6-channel data frame via serial
11. Wait for next interrupt
```

**Safety features:**
- Voltage limiting (VLIMIT) prevents excessive motor speed
- Automatic motor shutoff if both sensors read < 0.02 (pendulum fallen)
- LED indicators show system status
- Can be stopped by sending any character via serial

### 3_six_channel_oscilloscope.bin (pre-compiled binary)
**What it is:**
- Pre-compiled executable with default control parameters
- Ready to flash for immediate testing

**Default parameters:**
- KP = 1.0 (proportional gain)
- KD = 0.0 (derivative gain - initially disabled)
- VLIMIT = 0.1 (10% of maximum voltage)
- SAMP_FREQ = 2000 Hz

**How to use:**
1. Connect mbed to PC via USB
2. Drag and drop `3_six_channel_oscilloscope.bin` onto mbed drive
3. Press reset button on mbed
4. Control loop starts after 1 second delay

**When to compile .cpp yourself:**
- Want to adjust control gains (KP, KD)
- Need to change voltage limit (VLIMIT)
- Want to modify sampling frequency
- Need to add filtering or other control features
- Want to change which data is displayed on each channel

### 3_six_channel_oscilloscope.pde (Processing visualizer)
**What it does:**
- Receives 6-channel data frames from mbed
- Displays data in two 3-channel plots (upper and lower)
- Provides real-time visualization of control system state
- Essential for parameter tuning and debugging

**Display Layout:**
```
┌─────────────────────────────┐
│  Upper Plot (3 channels)    │
│  Red:   CH1 (pd1)           │
│  Green: CH2 (pd2)           │
│  Blue:  CH3 (angle)         │
├─────────────────────────────┤
│  Lower Plot (3 channels)    │
│  Red:   CH4 (omega)         │
│  Green: CH5 (filtered ω)    │
│  Blue:  CH6 (reference)     │
└─────────────────────────────┘
```

**Features:**
- Automatic scrolling time-series display
- Color-coded channels for easy identification
- Frame synchronization using header detection
- Handles high-speed data (2000 frames/second)

**How to use:**
1. Install Processing from https://processing.org/download
2. Open `3_six_channel_oscilloscope.pde` in Processing
3. Verify serial port name in code
4. Click Run button (▶) to start visualization
5. **Important:** Reset mbed after starting Processing to synchronize display
6. Observe system behavior while tuning control parameters

## Usage Workflow

### Initial Setup:
1. **Assemble complete circuit:**
   - Motor driver connected to p13, p14, p18
   - Photo-interrupters connected to p19, p20
   - Power supply connected (battery box)
   - All connections verified

2. **Flash program:**
   - Copy `3_six_channel_oscilloscope.bin` to mbed
   - Press reset button
   - Wait 1 second (idle period)

3. **Start visualizer:**
   - Run `3_six_channel_oscilloscope.pde` in Processing
   - Reset mbed to synchronize display
   - Observe 6-channel display

### Zeroing the Angle Sensor:
1. **Disconnect motor** (to prevent movement during adjustment)
2. Connect USB cable to mbed
3. Reset mbed, turn on battery box within 1 second
4. Hold pendulum vertical by hand
5. Observe CH3 (blue line, upper screen)
6. Should be approximately at center (128)
7. If not centered, adjust sensor bracket angle carefully
8. Repeat until angle reads ~0 (center) when vertical

### Testing with Proportional Control:
1. Turn off battery box, reconnect motor
2. Reset mbed, turn on battery box within 1 second
3. Stand pendulum vertical
4. Control starts after 1 second
5. Observe system response on oscilloscope:
   - CH3 (angle) should stay near center
   - CH4 (omega) shows angular velocity oscillations
   - Motor LEDs show control effort

### Tuning Control Gains:

**Step 1: Adjust KP (Proportional Gain)**
- Start with KP = 1.0, KD = 0.0
- If oscillation is slow (~1-2 Hz): increase KP
- If oscillation is fast and violent (>5 Hz): decrease KP
- Goal: Find KP where oscillation frequency is moderate (~3-4 Hz)

**Step 2: Add KD (Derivative Gain)**
- Once KP is reasonable, add KD gradually
- Start with KD = 0.1, increase slowly
- KD adds damping, reduces oscillation
- Too much KD causes instability (high-frequency noise amplification)
- Goal: Minimize oscillation while maintaining stability

**Step 3: Adjust VLIMIT**
- If motor saturates (LED2 on constantly): increase VLIMIT
- If motor is too aggressive: decrease VLIMIT
- Typical range: 0.05 - 0.2

**Step 4: Add Filtering (if needed)**
- If angular velocity (CH4) is very noisy, add low-pass filter
- Modify code to implement filtering (see below)
- Monitor CH5 (filtered omega) vs CH4 (raw omega)
- Adjust filter cutoff frequency to balance noise vs delay

## Testing Checklist

Use this tool to verify:
- [ ] Sensors read correctly (CH1, CH2 change with angle)
- [ ] Angle calculation is correct (CH3 centered when vertical)
- [ ] Motor responds to angle error (moves to correct tilt)
- [ ] Control loop runs at 2000 Hz (smooth display)
- [ ] No excessive oscillation or instability
- [ ] Voltage limiting works (LED2 indicates saturation)
- [ ] Motor stops when pendulum falls (safety feature)
- [ ] Can achieve stable balancing with tuned gains

## Troubleshooting

**Pendulum moves opposite to tilt (wrong direction):**
- Motor connections reversed
- Turn off power, swap motor wires
- Or swap p13 ↔ p14 connections

**High-frequency vibration (~5+ Hz):**
- KP gain too high
- Decrease KP by 20-50%
- May also indicate mechanical issues (loose connections)

**Slow oscillation, cannot stabilize:**
- KP gain too low
- Increase KP gradually
- Check motor has sufficient power

**Excessive noise in angular velocity:**
- Sensor signal quality issues
- Add low-pass filter to omega
- Check sensor connections and resistor values
- Route wires away from motor power

**Motor saturates constantly (LED2 always on):**
- VLIMIT too low for current gains
- Increase VLIMIT
- Or decrease control gains (KP, KD)

**Display not synchronized:**
- Reset mbed after starting Processing
- Check baud rate matches (230400)
- Verify USB cable quality

**Control loop seems slow or irregular:**
- Check SAMP_FREQ is 2000 Hz
- Ensure no blocking code in interrupt
- Verify timer interrupt is attached correctly

## Technical Details

### Control Algorithm

**PD Control:**
```
u(t) = KP × e(t) + KD × de/dt

where:
  u(t)   = control output (motor voltage)
  e(t)   = error (angle from vertical)
  de/dt  = rate of change of error (angular velocity)
  KP     = proportional gain
  KD     = derivative gain
```

**Implementation:**
```cpp
// Read sensors
float pd1v = pd1.read();
float pd2v = pd2.read();

// Calculate angle (error)
angle = pd1v - pd2v;

// Calculate angular velocity (derivative)
omega = (angle - angle_prev) * SAMP_FREQ;
angle_prev = angle;

// Control output
v_out = angle * KP + omega * KD;

// Apply to motor with direction and limiting
if (v_out > 0.0f) {
    motor_f = 1; motor_r = 0;
} else {
    motor_f = 0; motor_r = 1;
    v_out = -v_out;
}
if (v_out > VLIMIT) v_out = VLIMIT;
motor_v = v_out;
```

### Data Encoding

**Channels 1-2 (sensor readings):**
```cpp
// 0.0-1.0 → 0-255
uint8_t float01_to_u8(float x) {
    if (x < 0.0f) x = 0.0f;
    if (x > 1.0f) x = 1.0f;
    return (uint8_t)(x * 255.0f + 0.5f);
}
```

**Channel 3 (angle, signed):**
```cpp
// -1.0 to +1.0 → 0-255 (centered at 128)
uint8_t signed1_to_u8(float x) {
    int v = (int)(x * 127.0f + 128.0f + 0.5f);
    if (v < 0) return 0;
    if (v > 255) return 255;
    return (uint8_t)v;
}
```

**Channels 4-5 (angular velocity, scaled):**
```cpp
// omega with scale factor → 0-255 (centered at 128)
uint8_t omega_to_u8(float x, float scale) {
    int v = (int)(x * scale + 128.0f + 0.5f);
    if (v < 0) return 0;
    if (v > 255) return 255;
    return (uint8_t)v;
}
```
- Scale factor = 10.0 for typical omega range
- Adjust if omega values are too small or too large

### Interrupt-Based Control

**Why use interrupts?**
- Ensures precise timing (exactly 2000 Hz)
- Control loop runs independently of main program
- No timing drift or jitter

**Ticker setup:**
```cpp
Ticker t_int;
t_int.attach(&int0, 1.0f / SAMP_FREQ);
```
- Calls `int0()` function every 500 μs
- High priority, preempts main loop

**Important:** Keep interrupt handler fast!
- No `printf()` in interrupt (too slow)
- Use `pc.putc()` for single bytes only
- Avoid complex calculations
- Total execution time should be << 500 μs

### LED Indicators

- **LED1 (led_blink)**: Blinks at 1 Hz to show program is running
- **LED2 (led_v_over)**: On when motor voltage is saturated (hitting VLIMIT)
- **LED3 (led_v_forward)**: Brightness proportional to forward voltage
- **LED4 (led_v_backward)**: Brightness proportional to backward voltage

## Modifying the Code

### Change control gains:
```cpp
#define KP 2.5f   // Increase proportional gain
#define KD 0.3f   // Add derivative gain
```

### Add low-pass filter:
```cpp
// At top of file
#define FILTER_ALPHA 0.1f  // Filter coefficient (0-1)

// In int0() function, after calculating omega:
static float omega_filtered = 0.0f;
omega_filtered = FILTER_ALPHA * omega + (1.0f - FILTER_ALPHA) * omega_filtered;
f_omega = omega_filtered;
```

### Change voltage limit:
```cpp
#define VLIMIT 0.2f  // Increase to 20% of max
```

### Modify sampling frequency:
```cpp
#define SAMP_FREQ 1000.0f  // Reduce to 1 kHz
```
(May need to reduce baud rate if data transmission becomes unreliable)

### Add integral control (PID):
```cpp
// At top of file
#define KI 0.1f

// In int0() function
static float integral = 0.0f;
integral += angle / SAMP_FREQ;  // Integrate angle
v_out = angle * KP + f_omega * KD + integral * KI;
```

### Change which data is displayed:
```cpp
// In int0() function, modify the pc.putc() calls:
pc.putc((char)float01_to_u8(motor_v));     // CH1: motor voltage
pc.putc((char)signed1_to_u8(v_out));       // CH2: control output
pc.putc((char)signed1_to_u8(angle));       // CH3: angle
pc.putc((char)omega_to_u8(omega, 10.0f));  // CH4: omega
pc.putc((char)omega_to_u8(f_omega, 10.0f));// CH5: filtered omega
pc.putc((char)128);                        // CH6: reference
```

## Advanced Topics

### Filter Design

**First-order low-pass filter:**
```
y[n] = α × x[n] + (1-α) × y[n-1]

where:
  α = cutoff frequency / sampling frequency
  x[n] = input (current sample)
  y[n] = output (filtered value)
  y[n-1] = previous output
```

**Choosing α:**
- α = 0.1 → cutoff ≈ 200 Hz (strong filtering)
- α = 0.5 → cutoff ≈ 1000 Hz (mild filtering)
- Lower α = more filtering, more delay
- Higher α = less filtering, less delay

**Trade-off:**
- Too much filtering → slow response, instability
- Too little filtering → noise amplification, instability
- Goal: Filter just enough to remove high-frequency noise

### Baud Rate Calculation

**Data rate:**
- 6 bytes per frame + 2 header bytes = 8 bytes/frame
- 2000 frames/second × 8 bytes/frame = 16000 bytes/second
- 16000 bytes/second × 10 bits/byte (UART overhead) = 160000 bps

**Safety margin:**
- Use 230400 bps (1.44× required rate)
- Provides margin for processing delays
- Standard baud rate (well-supported)

**If you need higher sampling rate:**
- Reduce number of channels
- Increase baud rate (460800, 921600)
- Use more efficient encoding (not all platforms support)

### Motor Voltage Calculation

**Output voltage:**
```
V_motor = 3.3V × motor_v × 4 (driver gain)

Examples:
  motor_v = 0.1 → V_motor = 1.32V
  motor_v = 0.2 → V_motor = 2.64V
  motor_v = 1.0 → V_motor = 13.2V (max)
```

**VLIMIT interpretation:**
- VLIMIT = 0.1 → max 1.32V to motor
- VLIMIT = 0.2 → max 2.64V to motor
- Adjust based on battery voltage and motor specs

## Safety Notes

⚠️ **Important:**
- Always test with low gains first (KP = 0.5, KD = 0)
- Start with low VLIMIT (0.05-0.1)
- Hold pendulum when first testing
- Turn off battery box between tests
- Monitor motor driver temperature
- Be ready to catch falling pendulum
- Stop immediately if anything seems wrong

## Performance Tips

1. **Start conservative:** Low gains, low voltage limit
2. **Tune incrementally:** Change one parameter at a time
3. **Use oscilloscope:** Monitor all channels while tuning
4. **Document settings:** Record successful parameter combinations
5. **Test thoroughly:** Verify stability under various conditions

## See Also
- Main README: `../README.md`
- mbed Ticker API: https://os.mbed.com/docs/mbed-os/latest/apis/ticker.html
- PID Control Tutorial: https://en.wikipedia.org/wiki/PID_controller
- Digital Filter Design: https://en.wikipedia.org/wiki/Digital_filter

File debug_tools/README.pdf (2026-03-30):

# Debug Tools for Inverted Pendulum

This directory contains three debugging tools for the wheeled inverted pendulum experiment. Each tool consists of:

.cpp file: mbed microcontroller program (C++ source code)
.bin file: Pre-compiled binary ready to flash to mbed LPC1768
.pde file: Processing visualization program (runs on PC)

# Tools Overview

## 1. Motor Controller ( motor_controller/ )

Purpose: Test motor driver circuit and control motor interactively

mbed Program ( motor_controller.cpp ):

Receives commands via USB serial (115200 baud) Commands:
F xx - Forward at xx% duty cycle (0-100) B xx - Backward at xx% duty cycle (0-100) S - Stop motor
Pin connections:
p13 : Motor forward signal
p14 : Motor reverse signal
p18 : Motor PWM voltage (AnalogOut)

Processing Visualizer ( motor_controller.pde ):

Provides GUI with sliders and buttons Displays real-time motor status
Sends commands to mbed via serial
Usage:
1. Flash motor_controller.bin to mbed (or compile .cpp yourself)
2. Connect motor driver circuit
3. Run motor_controller.pde in Processing
4. Use GUI to test motor operation

## 2. Analog Input Visualizer ( analog_input_visualizer/ )

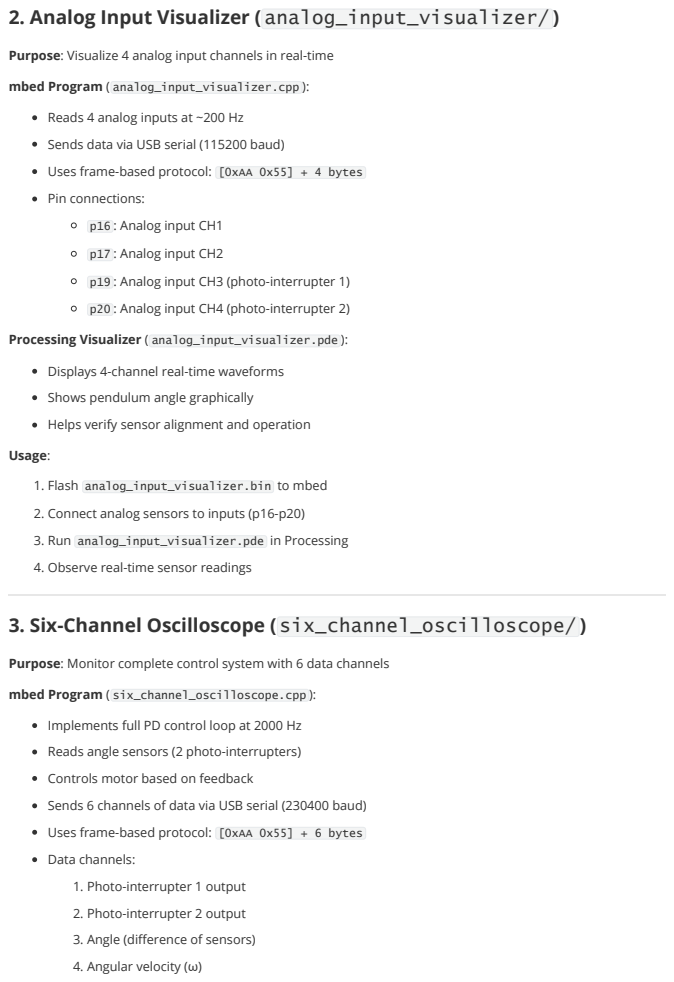
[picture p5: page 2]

Purpose: Visualize 4 analog input channels in real-time

mbed Program ( analog_input_visualizer.cpp ):
Reads 4 analog inputs at ~200 Hz
Sends data via USB serial (115200 baud)
Uses frame-based protocol: [0xAA 0x55] + 4 bytes
Pin connections:
p16 : Analog input CH1
p17 : Analog input CH2
p19 : Analog input CH3 (photo-interrupter 1)
p20 : Analog input CH4 (photo-interrupter 2)

Processing Visualizer ( analog_input_visualizer.pde ):
Displays 4-channel real-time waveforms
Shows pendulum angle graphically
Helps verify sensor alignment and operation
Usage:

1. Flash analog_input_visualizer.bin to mbed
2. Connect analog sensors to inputs (p16-p20)

3. Run analog_input_visualizer.pde in Processing
4. Observe real-time sensor readings

3. Six-Channel Oscilloscope ( six_channel_oscilloscope/ )

Purpose: Monitor complete control system with 6 data channels

mbed Program ( six_channel_oscilloscope.cpp ):
Implements full PD control loop at 2000 Hz
Reads angle sensors (2 photo-interrupters)
Controls motor based on feedback
Sends 6 channels of data via USB serial (230400 baud)
Uses frame-based protocol: [0xAA 0x55] + 6 bytes
Data channels:
1. Photo-interrupter 1 output
2. Photo-interrupter 2 output
3. Angle (difference of sensors)
4. Angular velocity (ω)

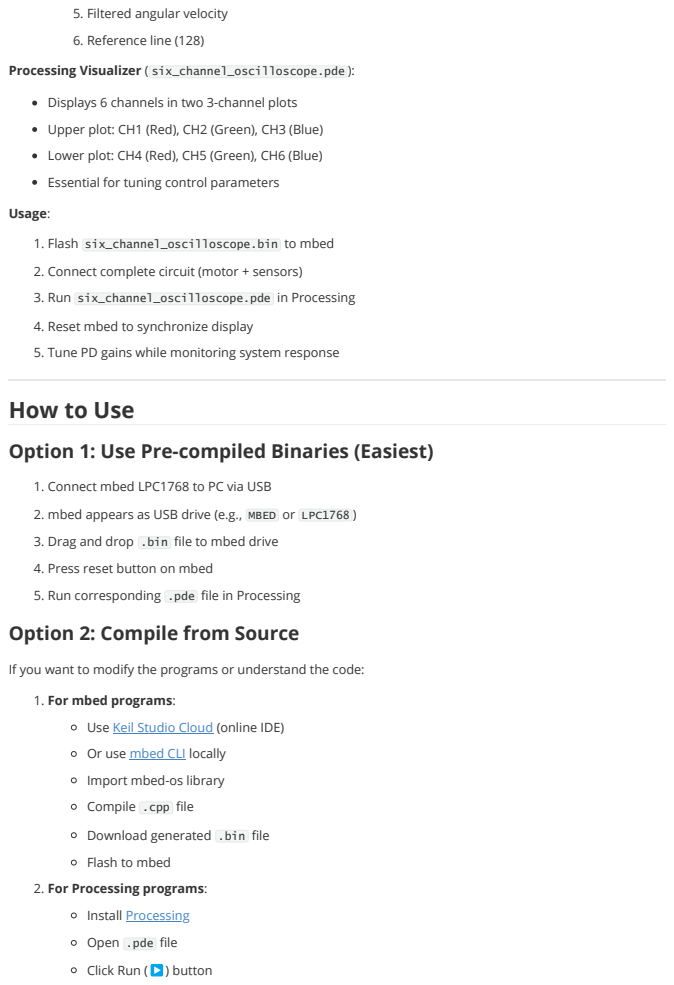
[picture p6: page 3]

5. Filtered angular velocity
6. Reference line (128)

Processing Visualizer ( six_channel_oscilloscope.pde ):

Displays 6 channels in two 3-channel plots
Upper plot: CH1 (Red), CH2 (Green), CH3 (Blue)
Lower plot: CH4 (Red), CH5 (Green), CH6 (Blue)
Essential for tuning control parameters
Usage:

1. Flash six_channel_oscilloscope.bin to mbed
2. Connect complete circuit (motor + sensors)

3. Run six_channel_oscilloscope.pde in Processing
4. Reset mbed to synchronize display
5. Tune PD gains while monitoring system response
How to Use
Option 1: Use Pre-compiled Binaries (Easiest)

1. Connect mbed LPC1768 to PC via USB
2. mbed appears as USB drive (e.g., MBED or LPC1768 )
3. Drag and drop .bin file to mbed drive
4. Press reset button on mbed
5. Run corresponding .pde file in Processing
Option 2: Compile from Source

If you want to modify the programs or understand the code:
1. For mbed programs:

Use Keil Studio Cloud (https://studio.keil.arm.com/) (online IDE)
Or use mbed CLI (https://os.mbed.com/docs/mbed-os/latest/build-tools/index.html) locally
Import mbed-os library
Compile .cpp file
Download generated .bin file
Flash to mbed

2. For Processing programs:

Install Processing (https://processing.org/download)
Open .pde file
Click Run (▶) button

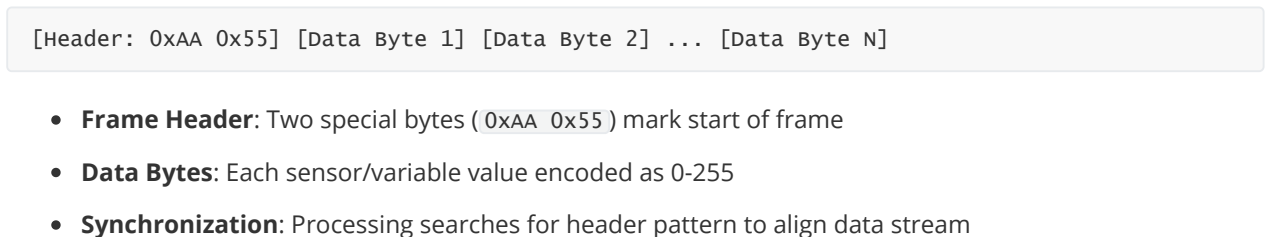
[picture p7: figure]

Function | Pin | Type | Used By
Motor Forward | p13 | DigitalOut | Motor Controller, Oscilloscope
Motor Reverse | p14 | DigitalOut | Motor Controller, Oscilloscope
Motor Voltage | p18 | AnalogOut | Motor Controller, Oscilloscope
Analog CH1 | p16 | AnalogIn | Analog Input Visualizer

Select correct serial port in code if needed

# Serial Communication Protocol

All tools use USB serial communication between mbed and PC:

## Basic Principle

UART (Universal Asynchronous Receiver-Transmitter): Serial protocol for byte-by-byte data transmission
USB-to-Serial: mbed LPC1768 has built-in USB-to-serial converter
Pins: USBTX and USBRX connect to USB interface
Baud Rate: Communication speed (bits per second)
Motor Controller: 115200 bps
Analog Input Visualizer: 115200 bps
Oscilloscope: 230400 bps (higher for 2 kHz data rate)

## Frame-Based Protocol (Visualizers)

To reliably transmit multiple data values, a frame-based protocol is used:

Frame Header: Two special bytes ( 0xAA 0x55 ) mark start of frame
Data Bytes: Each sensor/variable value encoded as 0-255
Synchronization: Processing searches for header pattern to align data stream

## Text-Based Protocol (Motor Controller)

Simple ASCII commands for human readability:

Commands sent as text strings (e.g., "F 50\n" )
Easy to test with any serial terminal
mbed parses commands using sscanf()

# Pin Assignments Summary

[Header: 0xAA 0x55] [Data Byte 1] [Data Byte 2] ... [Data Byte N]

Function | Pin | Type | Used By
Analog CH2 | p17 | AnalogIn | Analog Input Visualizer
Photo-interrupter 1 | p19 | AnalogIn | Analog Input Visualizer, Oscilloscope
Photo-interrupter 2 | p20 | AnalogIn | Analog Input Visualizer, Oscilloscope
USB Serial TX | USBTX | Serial | All tools
USB Serial RX | USBRX | Serial | All tools

Note: p18 is the only AnalogOut pin on mbed LPC1768, so motor voltage control must use this pin.

# Troubleshooting

## mbed not recognized as USB drive

Try different USB cable (some cables are power-only) Press reset button on mbed
Check USB port on PC

## Processing cannot find serial port

Check port name in .pde file (usually auto-detected) On Windows: Look for COM3 , COM4 , etc.

On macOS: Look for /dev/tty.usbmodem*
On Linux: Look for /dev/ttyACM*
Ensure no other program is using the port

## No data displayed in Processing

Reset mbed after starting Processing program
Check baud rate matches between mbed and Processing Verify USB cable supports data (not just power)

## Motor moves opposite direction

Swap motor driver connections ( p13 ↔ p14 ) Or swap motor wire polarity

## Sensor readings look wrong

Check sensor power supply (3.3V, not 5V) Verify pull-up resistors are installed Adjust sensor alignment mechanically

Check resistor values (typical: 1kΩ - 12kΩ)

# Modifying the Programs

## Changing Control Parameters (Oscilloscope)

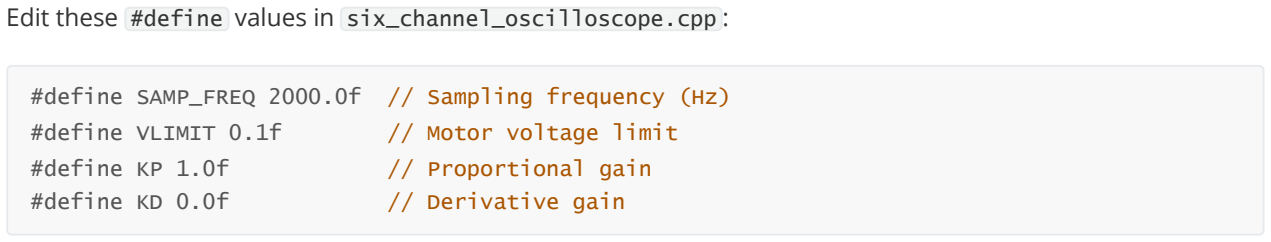
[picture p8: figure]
#define VLIMIT 0.1f; // Motor voltage limit; #define KP 1.0f; // Proportional gain; #define KD 0.0f; // Derivative gain

Edit these #define values in six_channel_oscilloscope.cpp :

After changing, recompile and flash to mbed.

## Adding More Channels

The frame protocol can be extended:

1. Add more data bytes in mbed program after frame header
2. Update Processing to read additional bytes
3. Add visualization for new channels

## Changing Serial Baud Rate

Must match in both mbed and Processing:

mbed: pc.baud(115200);

Processing: myPort = new Serial(this, portName, 115200);

# Further Reading

mbed Serial API (https://os.mbed.com/docs/mbed-os/latest/apis/serial-uart-apis.html)
Processing Serial Library (https://processing.org/reference/libraries/serial/index.html)
UART Communication Basics (https://learn.sparkfun.com/tutorials/serial-communication)

# License

These tools are provided for educational purposes as part of the University of Tokyo wheeled inverted pendulum experiment.

#define SAMP_FREQ 2000.0f // Sampling frequency (Hz)

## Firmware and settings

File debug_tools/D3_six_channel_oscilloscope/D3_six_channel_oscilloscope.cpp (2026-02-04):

#include "mbed.h"

// Sampling frequency
#define SAMP_FREQ 2000.0f
// Motor voltage limit (V_motor = 3.3 * v_out * 4)
#define VLIMIT 0.1f
// Motor offset voltage
#define VOFFSET 0.0f
// Feedback gains (Arbitrary Unit)
#define KP 1.0f
#define KD 0.0f

// Frame header (2 bytes)
#define FRAME_H1 0xAA
#define FRAME_H2 0x55

// Define LEDs
PwmOut led_blink(LED1);             // Blink at 1 Hz during operation
PwmOut led_v_over(LED2);            // Indicate voltage saturation
PwmOut led_v_forward(LED3);         // Indicate voltage for forward motion
PwmOut led_v_backward(LED4);        // Indicate voltage for backward motion

// Define motor controls
DigitalOut motor_f(p13);            // Motor forward
DigitalOut motor_r(p14);            // Motor backward
AnalogOut motor_v(p18);             // Motor driving voltage

// Define Photo-diode readings for angle sensor
AnalogIn pd1(p19);
AnalogIn pd2(p20);

Serial pc(USBTX, USBRX);            // Serial communication
Ticker t_int;                       // Interrupt ticker

float brightness = 0.0f;            // Brightness for blinking led_blink
float br_inc = 1.0f / SAMP_FREQ;    // For blinking LED at 1 Hz
float angle = 0.0f, angle_prev = 0.0f;
float v_out = 0.0f;
float v_dir = 1.0f;
float omega = 0.0f;
float f_omega = 0.0f;

// ---- helpers: clamp and pack to uint8 ----
static inline uint8_t clamp_u8(int v) {
    if (v < 0) return 0;
    if (v > 255) return 255;
    return (uint8_t)v;
}

static inline uint8_t float01_to_u8(float x) {
    if (x < 0.0f) x = 0.0f;
    if (x > 1.0f) x = 1.0f;
    // *255 to avoid overflow at exactly 1.0
    return (uint8_t)(x * 255.0f + 0.5f);
}

// map approx [-1, +1] -> [0,255] (center 128)
static inline uint8_t signed1_to_u8(float x) {
    int v = (int)(x * 127.0f + 128.0f + 0.5f);
    return clamp_u8(v);
}

// omega -> [0,255] center 128 with scale factor
static inline uint8_t omega_to_u8(float x, float scale) {
    int v = (int)(x * scale + 128.0f + 0.5f);
    return clamp_u8(v);
}

// Interrupt handler (control loop)
void int0() {
    // Read photo-diodes (0..1)
    float pd1v = pd1.read();
    float pd2v = pd2.read();

    // angle: difference (-1..+1 roughly)
    angle = pd1v - pd2v;

    // omega
    omega = (angle - angle_prev) * SAMP_FREQ;
    angle_prev = angle;

    // filtering omega (currently none)
    f_omega = omega;

    // control output
    v_out = angle * KP + f_omega * KD;
    if (v_out > 0.0f) {
        motor_f = 1;
        motor_r = 0;
        v_dir = 1.0f;
    } else {
        motor_f = 0;
        motor_r = 1;
        v_out *= -1.0f;
        v_dir = -1.0f;
    }

    if (v_out > VLIMIT) {
        v_out = VLIMIT;
        led_v_over = 1;
    } else {
        led_v_over = 0;
    }

    // Motor output
    if (pd1v < 0.02f && pd2v < 0.02f) {   // if not standing, stop the motor
        motor_v = 0;
        led_v_forward = 1;
        led_v_backward = 1;
    } else {
        motor_v = v_out + VOFFSET;
        led_v_forward  = (v_dir > 0 ? v_out * 3.3f : 0.0f);
        led_v_backward = (v_dir < 0 ? v_out * 3.3f : 0.0f);
    }

    // blink LED
    brightness += br_inc;
    if (brightness >= 1.0f) brightness = 0.0f;
    led_blink = brightness;

    // ---- send one frame: [AA 55] + 6 bytes ----
    pc.putc((char)FRAME_H1);
    pc.putc((char)FRAME_H2);

    // CH1..CH6
    pc.putc((char)float01_to_u8(pd1v));            // CH1: pd1
    pc.putc((char)float01_to_u8(pd2v));            // CH2: pd2
    pc.putc((char)signed1_to_u8(angle));           // CH3: angle
    pc.putc((char)omega_to_u8(omega, 10.0f));      // CH4: omega (scaled)
    pc.putc((char)omega_to_u8(f_omega, 10.0f));    // CH5: f_omega (scaled)
    pc.putc((char)128);                            // CH6: reference line
}

int main() {
    // Initializing LED PWM periods and Serial port
    led_blink.period(1.0f / SAMP_FREQ);
    led_v_over.period(1.0f / SAMP_FREQ);
    led_v_forward.period(1.0f / SAMP_FREQ);
    led_v_backward.period(1.0f / SAMP_FREQ);

    pc.baud(230400);

    wait(1);

    // Optional: keep this if your old Processing uses it, but it WILL confuse frame parsing
    // If you switch to frame-header parsing, you can comment this out.
    // pc.printf("12345678");

    // Start Control
    t_int.attach(&int0, 1.0f / SAMP_FREQ);

    // Keep running; do NOT echo back (echo can corrupt framing)
    while (1) {
        // If you want to stop on any received byte, consume without echo:
        if (pc.readable()) {
            (void)pc.getc();
            t_int.detach();
            break;
        }
    }
}

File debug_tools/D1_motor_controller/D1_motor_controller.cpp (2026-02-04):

#include "mbed.h"

DigitalOut motor_f(p13);
DigitalOut motor_r(p14);
AnalogOut  motor_v(p18);

Serial pc(USBTX, USBRX);

static void apply_stop() {
    motor_f = 0; motor_r = 0; motor_v = 0.0f;
}

static void apply_fwd(int pct) {
    float duty = pct / 100.0f;
    motor_f = 1; motor_r = 0; motor_v = duty;
}

static void apply_bwd(int pct) {
    float duty = pct / 100.0f;
    motor_f = 0; motor_r = 1; motor_v = duty;
}

int main() {
    pc.baud(115200);
    apply_stop();
    pc.printf("Motor control ready\r\n");
    pc.printf("Commands: F xx | B xx | S\r\n");

    char line[64];
    int idx = 0;

    while (1) {
        if (!pc.readable()) continue;

        char c = pc.getc();
        if (c == '\r') continue;

        if (c == '\n') {
            line[idx] = '\0';
            idx = 0;

            char cmd = 0;
            int value = 0;

            // 支持："F 30" / "B 80" / "S"
            if (sscanf(line, " %c %d", &cmd, &value) >= 1) {
                if (cmd == 'F' || cmd == 'f') {
                    if (value < 0) value = 0;
                    if (value > 100) value = 100;
                    apply_fwd(value);
                    pc.printf("Forward: %d%%\r\n", value);
                } else if (cmd == 'B' || cmd == 'b') {
                    if (value < 0) value = 0;
                    if (value > 100) value = 100;
                    apply_bwd(value);
                    pc.printf("Backward: %d%%\r\n", value);
                } else if (cmd == 'S' || cmd == 's') {
                    apply_stop();
                    pc.printf("Stop\r\n");
                } else {
                    pc.printf("Unknown cmd: %c\r\n", cmd);
                }
            }
        } else {
            if (idx < (int)sizeof(line) - 1) line[idx++] = c;
            else idx = 0; // overflow -> reset
        }
    }
}

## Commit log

2026-02-04 Course materials 2026
2026-02-23 Update Simulink models and Fritzing assets
    [Main.fzz]
2026-03-30 Rename debug_tools subdirs/files with D prefix; update PDFs
    - Renamed 1_*/2_*/3_* folders and files to D1_*/D2_*/D3_* to avoid digit-leading names
    - Updated text2026_en.pdf, debug_tools/README.pdf
    - Added text2026_jp.pdf
    [D1_motor_controller.cpp, D1_motor_controller.pde, D2_analog_input_visualizer.pde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]
2026-03-30 Add GitHub Pages site (docs/) with EN/JP online reading
    - index.html: bilingual landing page with course outline
    - en.html / jp.html: pandoc-converted HTML with MathJax, nav bar, PDF links
    - style.css: unified site styles
    - docs/figs/: figures for HTML rendering
    - docs/text2026_en.pdf / text2026_jp.pdf: downloadable PDFs
2026-04-26 Add Fritzing demo files and guide videos (4-6); remove PDF lecture notes
    [Main_Demo.fzz, Step1.fzz, Step2.fzz]
